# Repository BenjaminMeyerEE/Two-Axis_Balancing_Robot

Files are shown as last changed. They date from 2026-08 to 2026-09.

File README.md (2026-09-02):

# Two-Axis Balancing Robot

A robot that balances in pitch and roll. The two axes use different hardware: pitch
runs a brushless motor through a VESC over CAN, roll runs a brushed motor through an
H-bridge on a custom power board. Both close around an STM32G474 and an ICM-42688-P
IMU on a custom carrier board. Two custom 4-layer boards, designed in KiCad.

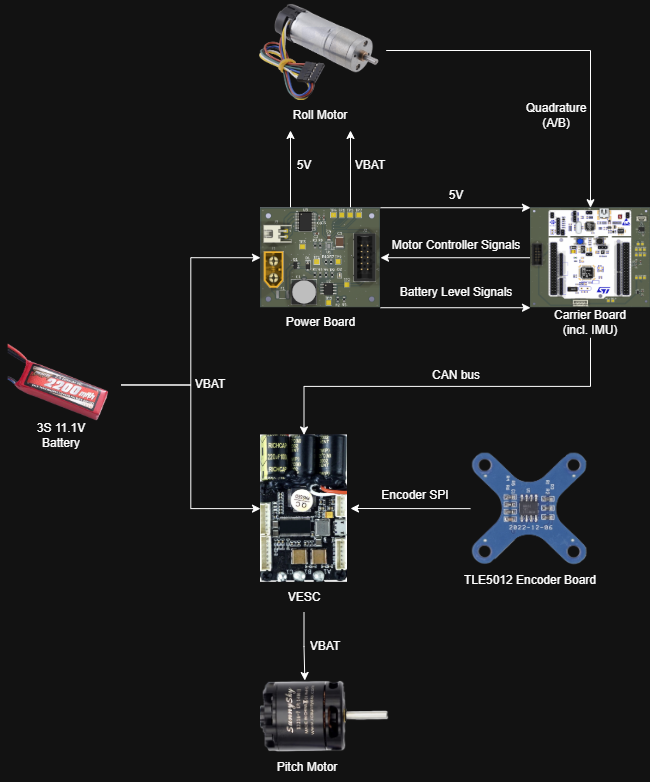
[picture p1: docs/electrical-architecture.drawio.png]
Electrical architecture


<!-- TODO
     - mechanical: CAD screenshots once the design is finished
     - the Simulink model and the LQR weight-selection model, once cleaned up
     - fp-lib-table on both boards points at C:/Users/brmey/Downloads, so footprint
       libraries won't resolve on another machine
     - the carrier render uses a Nucleo-64 F401 STEP as a stand-in; same form factor
       as the G474RE but the silkscreen says F411 if you look closely
     images are generated, see docs/regenerate-images.md
-->

## Specifications

| Parameter | Value |
|---|---|
| Axes | Pitch and roll, separate drive hardware |
| Controller | STM32G474RET6 (Nucleo-G474RE on the carrier board) |
| IMU | ICM-42688-P over SPI, both interrupt lines broken out |
| Pitch drive | Brushless motor via VESC, commanded over CAN |
| Pitch feedback | TLE5012 magnetic encoder, SPI to the VESC |
| Roll drive | Brushed motor via TB6612FNG dual H-bridge |
| Roll feedback | Quadrature encoder into the carrier board |
| Battery | 3S LiPo, 11.1 V nominal |
| Carrier board | 101.6 × 92.9 mm, 4-layer |
| Power board | 50.0 × 42.9 mm, 4-layer |

## Status

Both custom PCBs are designed and the electrical architecture is laid out. Mechanical
design is partly finished.

I simulated the pitch axis in Simulink first, and that's what pushed me away from PID and toward LQR. Wheel position and tilt are coupled through the dynamics, so tuning them as separate loops meant the two kept fighting each other — full state feedback made more sense than trying to manage that interaction by hand. What I'm working on now is deriving the equations of motion using Lagrangian mechanics, linearizing about the upright equilibrium, and designing a discrete-time LQR, using Bryson's rule to set the cost weights. This is all being done in MATLAB

## Repository layout

| Path | Contents |
|---|---|
| `hardware/two_axis_balancing_carrier/` | Carrier board KiCad project |
| `hardware/two_axis_balancing_power/` | Power board KiCad project |
| `docs/` | Architecture diagram, board renders, layer plots |

## Hardware

Both boards are 4-layer. Every copper layer below is plotted from the top and
unmirrored, so features line up between layers.

### Carrier board

101.6 × 92.9 mm. Holds the Nucleo-G474RE and everything the control loop reads.

| | |
|---|---|
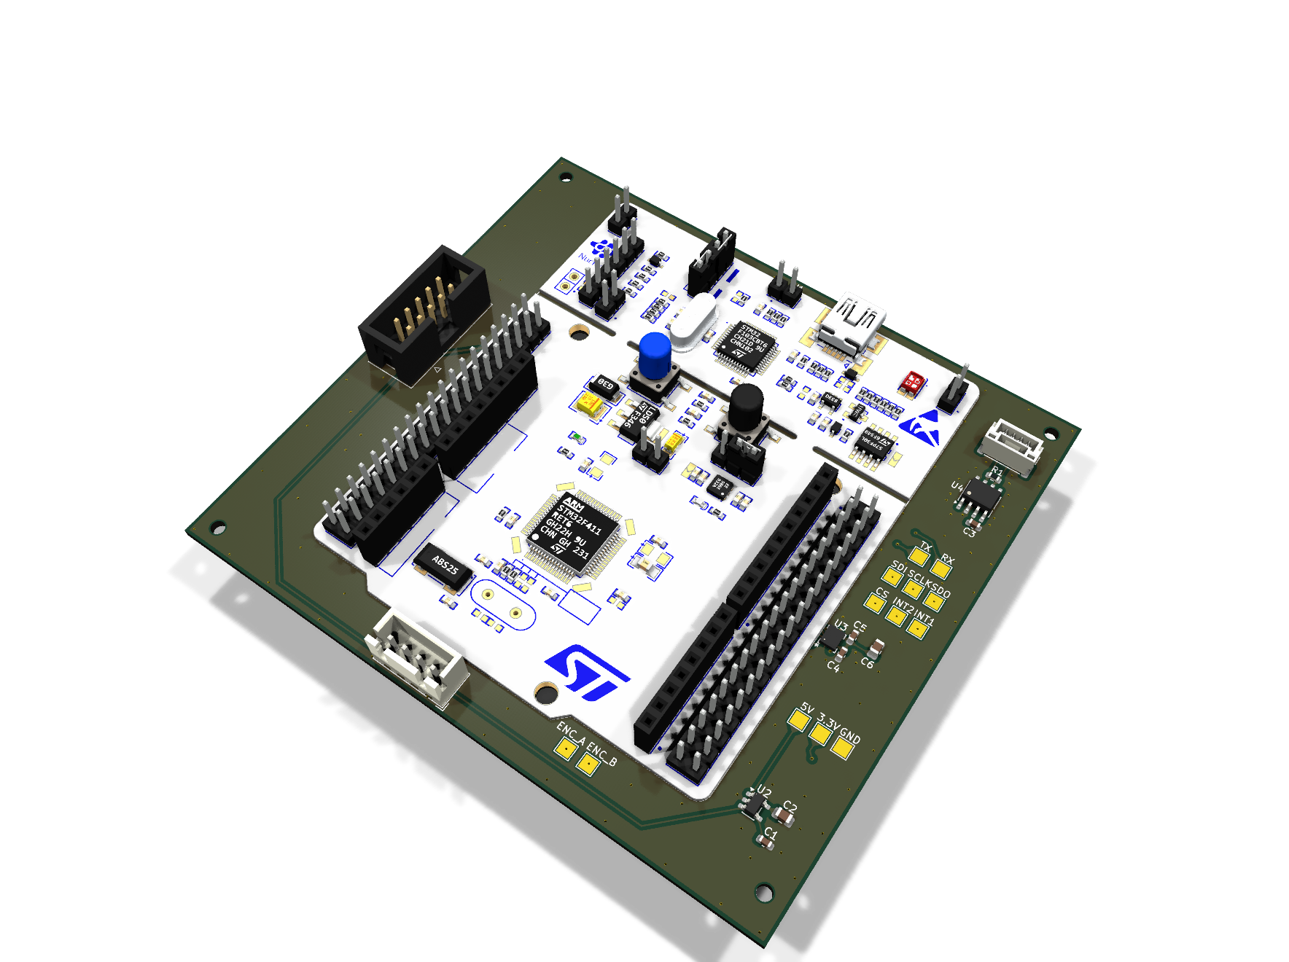
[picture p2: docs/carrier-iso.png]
Carrier board
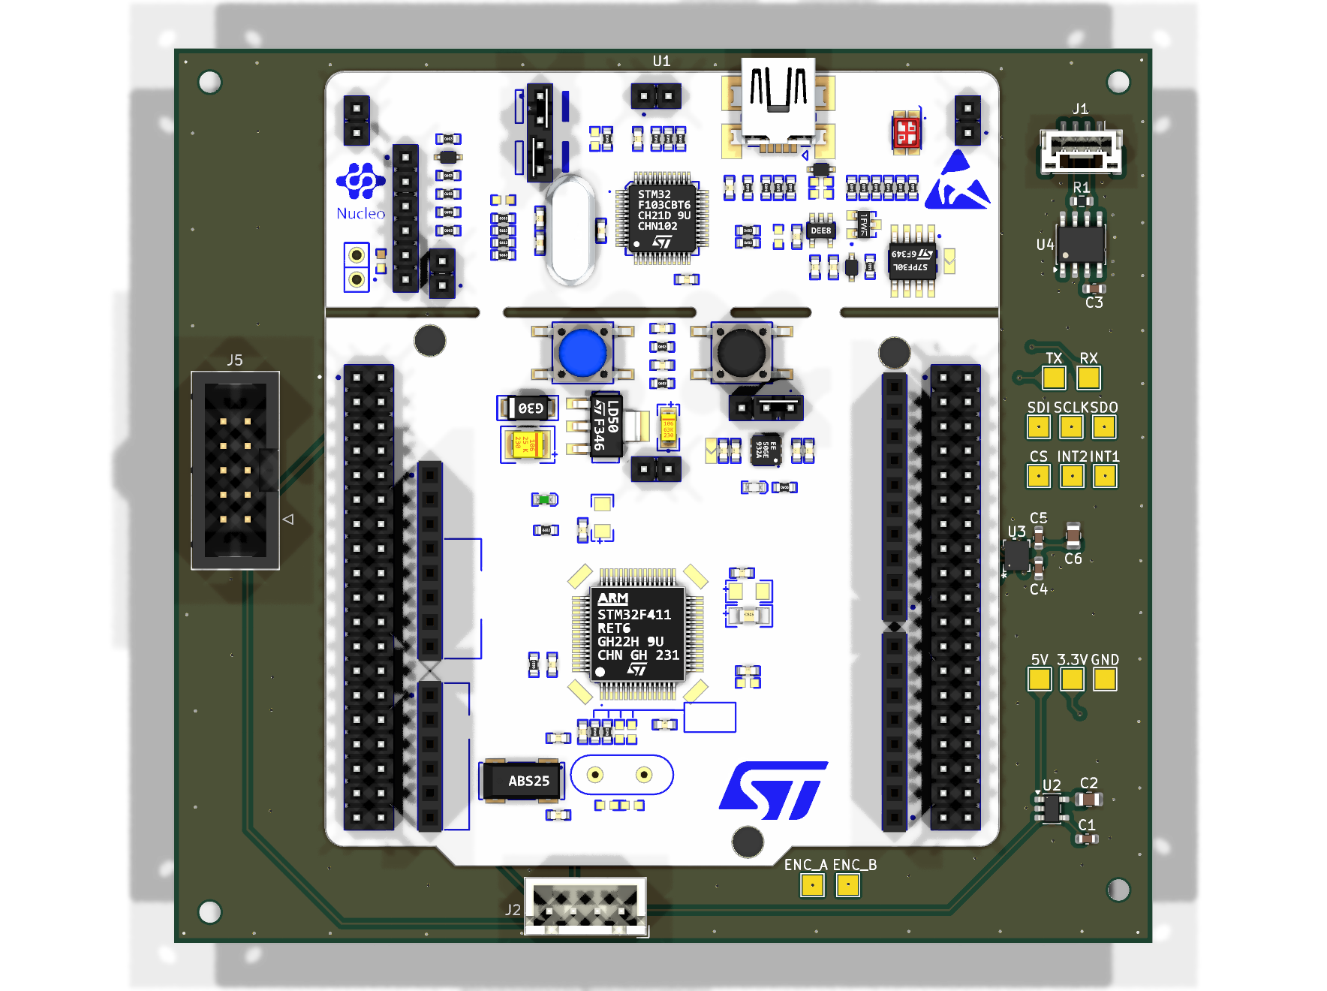
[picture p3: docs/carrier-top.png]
Carrier board, top
|  |  |

The ICM-42688-P is on SPI (`CS`, `SCLK`, `SDI`, `SDO`) with `INT1` and `INT2` brought
out, so the loop can run off data-ready rather than polling. An SN65HVD230 with 120 Ω
termination puts the board on the CAN bus to the VESC. A MIC5219-3.3 makes the 3.3 V
rail from the 5 V coming off the power board.

Roll encoder channels come in here on `ENC_A` / `ENC_B`. Motor commands (`AIN1`,
`AIN2`, `PWMA`, `STBY`) and the battery signals go back to the power board over a 2×5
IDC ribbon. There are 13 test points, and the SPI, UART, encoder and rail pads are all
labelled on the silkscreen for bring-up.

| `F.Cu` | `In1.Cu` |
|---|---|
| F.Cu | In1.Cu |

| `In2.Cu` | `B.Cu` |
|---|---|
| In2.Cu | B.Cu |

### Power board

50.0 × 42.9 mm. Takes the battery in and handles everything that touches VBAT.

| | |
|---|---|
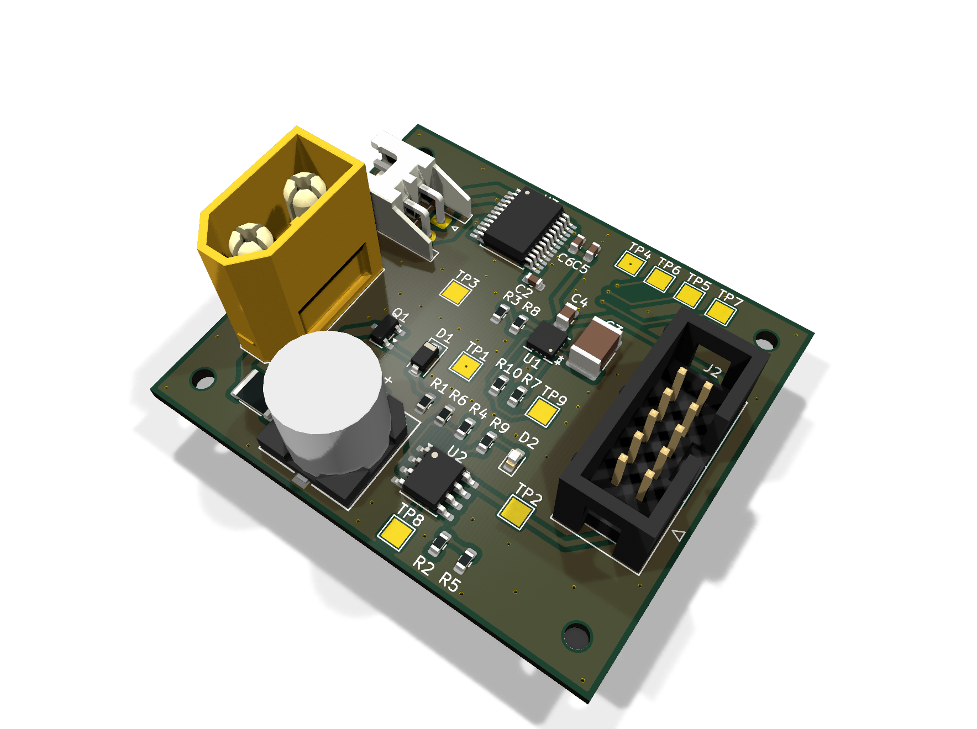
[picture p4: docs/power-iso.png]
Power board
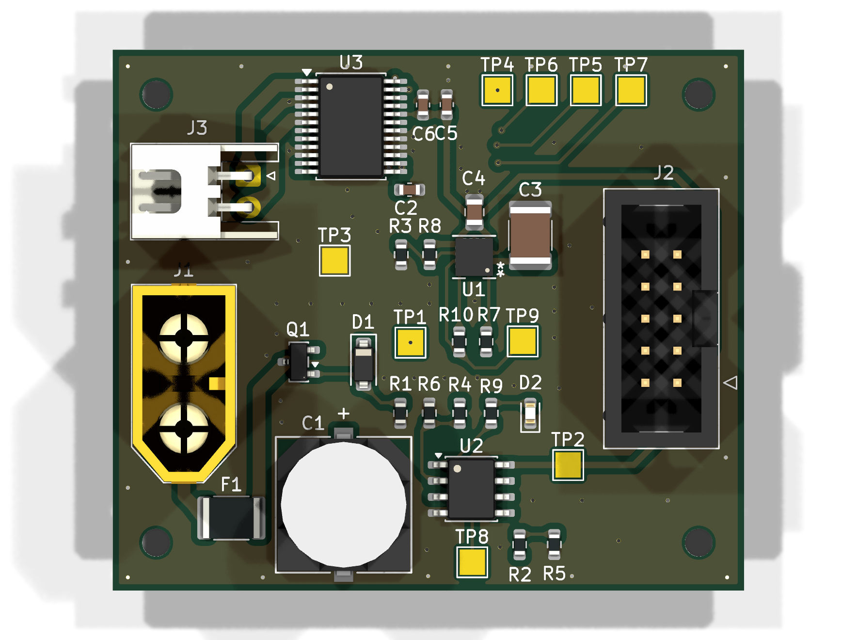
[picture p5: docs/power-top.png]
Power board, top
|  |  |

Battery comes in on an XT60, behind a 3 A fuse, an AO3401A P-channel MOSFET for
reverse polarity, and a 10 V zener. An RPL-1.0-R module makes the 5 V rail and reports
`Buck_PG` back to the MCU. A TB6612FNG dual H-bridge drives the roll motor on
`MOTOR_P` / `MOTOR_N`.

Battery monitoring is done on this board rather than in firmware. A divider gives
`BAT_LEV`, an LM393 compares it against `BAT_REF`, and `BAT_LOW` goes back to the
carrier board. The MCU sees both the raw level and a latched low flag.

| `F.Cu` | `In1.Cu` |
|---|---|
| F.Cu | In1.Cu |

| `In2.Cu` | `B.Cu` |
|---|---|
| In2.Cu | B.Cu |

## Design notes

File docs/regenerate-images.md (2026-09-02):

# Regenerating the images

Everything in `docs/` except the architecture diagram is generated from the board
files with `kicad-cli`, so it can be rebuilt after a layout change instead of
re-screenshotted.

On Windows the binary is at:

    "C:/Program Files/KiCad/10.0/bin/kicad-cli.exe"

Run from the repository root. `$N` is `power` or `carrier`, `$B` is the matching
project folder under `hardware/`.

## 3D renders

    kicad-cli pcb render -o docs/$N-iso.png --quality high --perspective \
      --rotate '-30,0,-35' --zoom 0.7 --width 1800 --height 1350 \
      --background transparent hardware/$B/$B.kicad_pcb

    kicad-cli pcb render -o docs/$N-top.png --side top --quality high \
      --width 1800 --height 1350 --background transparent \
      hardware/$B/$B.kicad_pcb

Transparent backgrounds are deliberate. They read correctly on both GitHub's light
and dark themes.

## Copper layers

One SVG per layer, with the board outline for reference:

    for lp in "F.Cu:f-cu" "In1.Cu:in1-cu" "In2.Cu:in2-cu" "B.Cu:b-cu"; do
      L="${lp%%:*}"; S="${lp##*:}"
      kicad-cli pcb export svg -o "docs/$N-layer-$S.svg" --mode-single \
        --layers "$L,Edge.Cuts" --exclude-drawing-sheet --page-size-mode 2 \
        --check-zones hardware/$B/$B.kicad_pcb
    done

Then darken the board outline, since KiCad plots `Edge.Cuts` as `#D0D2CD` which
disappears on a white page:

    sed -i 's/#D0D2CD/#555555/g' docs/*-layer-*.svg

Silkscreen is left out on purpose. KiCad plots it as `#F2EDA1`, which is effectively
invisible against GitHub's light background. `B.Cu` is not mirrored, so every layer
lines up with every other one.

## Notes

- `--check-zones` refills pours before plotting, so the layer images always match the
  current zone settings.
- Close the KiCad PCB editor first. `kicad-cli` reads from disk, and an open editor
  can overwrite the board file when it saves.
- Regenerating always shows every file as modified. Raytraced PNGs differ by a few
  hundred bytes between runs and the SVGs carry a timestamp, so use a diff of the
  drawing elements rather than `git status` to tell whether anything really changed.

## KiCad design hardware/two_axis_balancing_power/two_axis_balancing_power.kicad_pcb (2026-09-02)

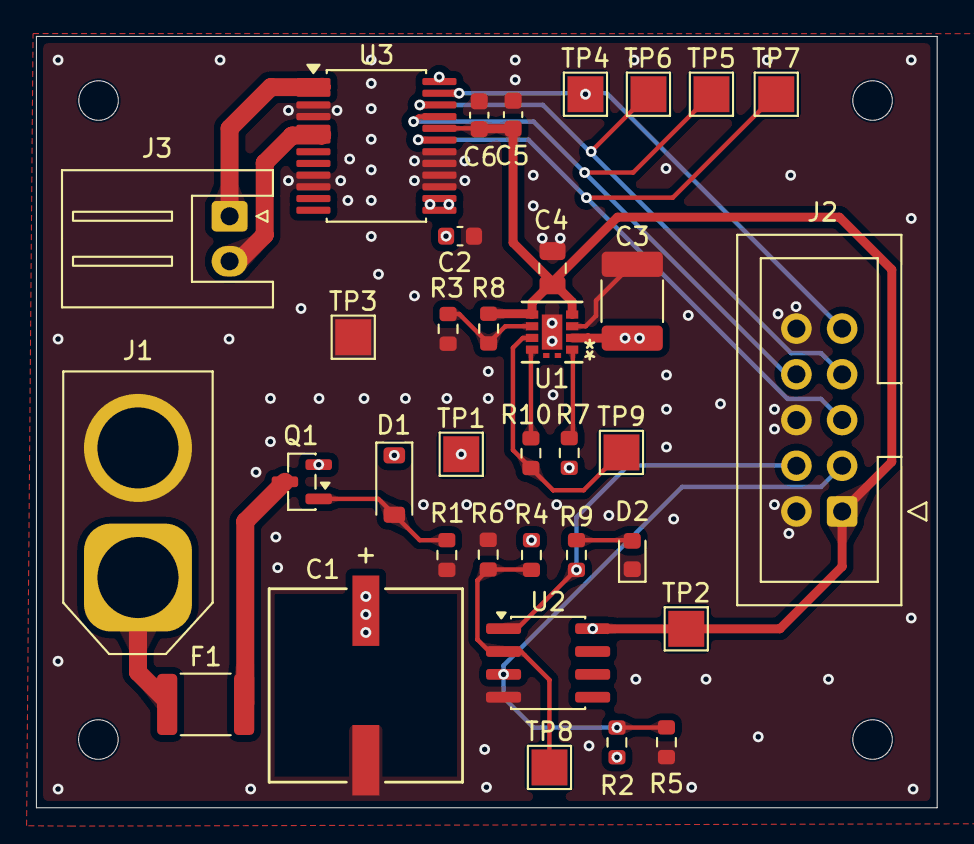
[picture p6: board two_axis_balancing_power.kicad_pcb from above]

Board: 4 copper layers, 50.0 x 42.9 mm, 35 parts (0 on the bottom side), 20 nets.

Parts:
C1: 470uF; PCAP_10x10-ELECT_NCA
C2, C6: 100nF; C_0603_1608Metric
C3: 20uF; C_1812_4532Metric
C4: 22uF; C_0805_2012Metric
C5: 10uF; C_0603_1608Metric
D1: 10V; D_SOD-123
D2: LED; LED_0603_1608Metric
F1: 3A; Fuse_1812_4532Metric
J1: Conn_01x02; AMASS_XT60-M_1x02_P7.20mm_Vertical
J2: Conn_02x05; IDC-Header_2x05_P2.54mm_Vertical
J3: Conn_01x02; JST_XH_S2B-XH-A_1x02_P2.50mm_Horizontal
Q1: AO3401A; SOT-23
R1, R4, R5: 10kR; R_0603_1608Metric
R2: 47kR; R_0603_1608Metric
R3: 220kR; R_0603_1608Metric
R6: 5.9kR; R_0603_1608Metric
R7, R10: 100kR; R_0603_1608Metric
R8: 1613kR; R_0603_1608Metric
R9: 220R; R_0603_1608Metric
TP1, TP2, TP3, TP4, TP5, TP6, TP7, TP8, TP9: TestPoint; TestPoint_Pad_2.0x2.0mm
U1: RPL-1.0-R; 11L-LGA-M_RPL-1_RCP
U2: LM393; SOIC-8_3.9x4.9mm_P1.27mm
U3: TB6612FNG; SSOP-24_5.3x8.2mm_P0.65mm

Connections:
+5V: C4.2, C5.2, C6.2, J2.1, R4.2, R8.2, TP2.1 (1_1), U1.4 (VOUT), U1.5 (VOUT), U2.8 (V+), U3.20 (VCC)
/AIN1: J2.8, TP5.1 (1_1), U3.21 (AIN1)
/AIN2: J2.7, TP6.1 (1_1), U3.22 (AIN2)
/BAT_LEV: J2.3, R2.1, R5.1, U2.3 (+)
/BAT_LOW: J2.4, R9.2, U2.1
/BAT_REF: R4.1, R6.1, TP8.1 (1_1), U2.2 (-)
/Buck_PG: R10.2, TP9.1 (1_1), U1.7 (PG)
/MOTOR_N: J3.2, U3.5 (AO2), U3.6 (AO2)
/MOTOR_P: J3.1, U3.1 (AO1), U3.2 (AO1)
/PWMA: J2.9, TP4.1 (1_1), U3.23 (PWMA)
/STBY: J2.5, TP7.1 (1_1), U3.19 (STBY)
GND: C1.2, C2.2, C3.1, C4.1, C5.1, C6.1, D2.1 (K), J1.2, J2.2, J2.6, J2.10, R1.2, R3.1, R5.2, R6.2, TP3.1 (1_1), U1.3 (PGND), U1.11 (TP), U2.4 (V-), U3.3 (PGND1), U3.4 (PGND1), U3.9 (PGND2), U3.10 (PGND2), U3.15 (PWMB), U3.16 (BIN2), U3.17 (BIN1), U3.18 (GND)
unnamed: D1.2 (A), Q1.1 (G), R1.1
unnamed: D2.2 (A), R9.1
unnamed: F1.1, J1.1
unnamed: F1.2, Q1.3 (D)
unnamed: R7.2, U1.1 (CTRL)
unnamed: R3.2, R8.1, U1.6 (FB)
unnamed: R10.1, U1.8 (VCC)
VBAT: C1.1, C2.1, C3.2, D1.1 (K), Q1.2 (S), R2.2, R7.1, TP1.1 (1_1), U1.2 (VIN), U3.13 (VM2), U3.14 (VM3), U3.24 (VM1)

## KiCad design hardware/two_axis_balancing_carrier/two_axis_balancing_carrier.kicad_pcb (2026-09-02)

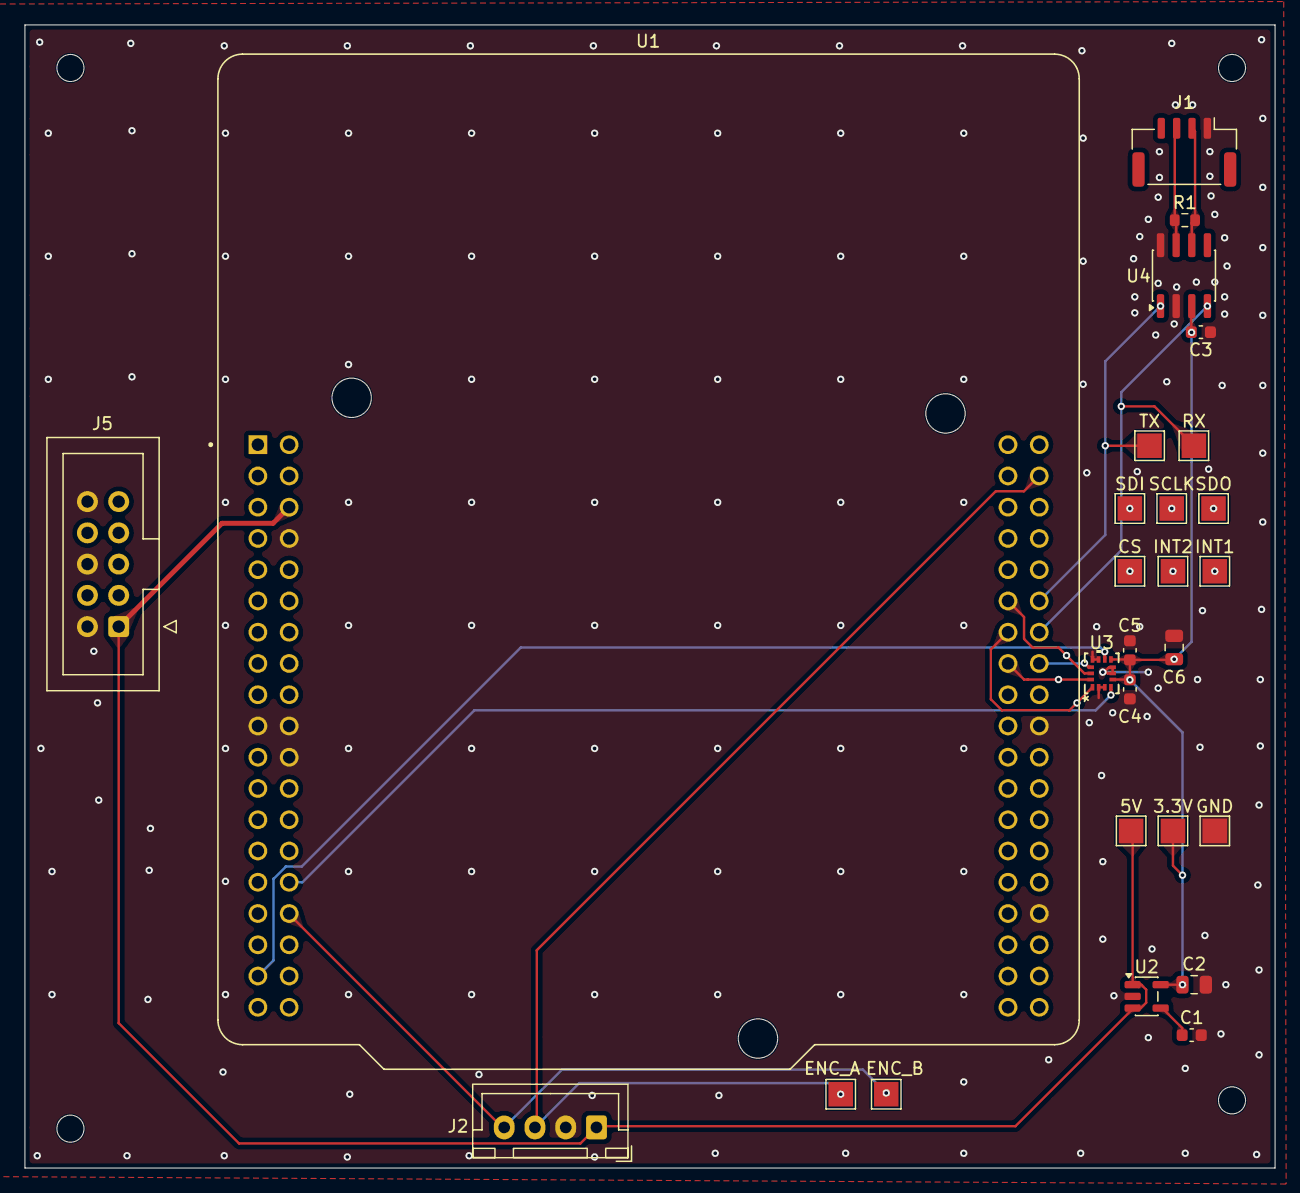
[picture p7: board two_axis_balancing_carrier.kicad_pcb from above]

Board: 4 copper layers, 101.6 x 92.9 mm, 27 parts (0 on the bottom side), 22 nets.

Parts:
3.3V, 5V: TestPoint; TestPoint_Pad_2.0x2.0mm
C1: 470pF; C_0603_1608Metric
C2, C6: 2.2uF; C_0805_2012Metric
C3, C5: 100nF; C_0603_1608Metric
C4: 10nF; C_0603_1608Metric
CS: TestPoint; TestPoint_Pad_2.0x2.0mm
ENC_A: TestPoint; TestPoint_Pad_2.0x2.0mm
ENC_B: TestPoint; TestPoint_Pad_2.0x2.0mm
GND: TestPoint; TestPoint_Pad_2.0x2.0mm
INT1, INT2: TestPoint; TestPoint_Pad_2.0x2.0mm
J1: Conn_01x03; JST_GH_BM04B-GHS-TBT_1x04-1MP_P1.25mm_Vertical
J2: Conn_01x04; JST_XH_B4B-XH-A_1x04_P2.50mm_Vertical
J5: Conn_02x05; IDC-Header_2x05_P2.54mm_Vertical
R1: 120R; R_0603_1608Metric
RX: TestPoint; TestPoint_Pad_2.0x2.0mm
SCLK: TestPoint; TestPoint_Pad_2.0x2.0mm
SDI: TestPoint; TestPoint_Pad_2.0x2.0mm
SDO: TestPoint; TestPoint_Pad_2.0x2.0mm
TX: TestPoint; TestPoint_Pad_2.0x2.0mm
U1: NUCLEO-G474RE; MODULE_NUCLEO-G474RE
U2: MIC5219-3.3YM5; SOT-23-5
U3: ICM-42688-P; LGA14_2P5X3X0P91_TDK
U4: SN65HVD230; SOIC-8_3.9x4.9mm_P1.27mm

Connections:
+3.3V: 3.3V.1 (1_1), C2.1, C3.1, C4.2, C5.1, C6.1, U2.5 (OUT), U3.5 (VDDIO), U3.8 (VDD), U4.3 (VCC)
+5V: 5V.1 (1_1), J2.1, J5.1, U1.CN7_6 (E5V), U2.1 (IN), U2.3 (EN)
/AIN1: J5.8, U1.CN7_23 (PC13)
/AIN2: J5.7, U1.CN7_25 (PC14)
/BAT_LEV: J5.3, U1.CN7_28 (PA0)
/BAT_LOW: J5.4, U1.CN7_37 (PC3)
/CANH: J1.3, R1.1, U4.7 (CANH)
/CANL: J1.2, R1.2, U4.6 (CANL)
/CS: CS.1 (1_1), U1.CN10_16 (PB12), U3.12 (AP_CS)
/ENC_A: ENC_A.1 (1_1), J2.3, U1.CN10_4 (PC6)
/ENC_B: ENC_B.1 (1_1), J2.4, U1.CN7_32 (PA4)
/INT1: INT1.1 (1_1), U1.CN7_30 (PA1), U3.4 (INT1/INT)
/INT2: INT2.1 (1_1), U1.CN7_35 (PC2), U3.9 (INT2/FSYNC/CLKIN)
/PWMA: J5.9, U1.CN7_38 (PC0/PA15)
/RX: RX.1 (1_1), U1.CN10_14 (PA11), U4.4 (R)
/SCLK: SCLK.1 (1_1), U1.CN10_11 (PA5), U3.13 (AP_SCL/AP_SCLK)
/SDI: SDI.1 (1_1), U1.CN10_15 (PA7), U3.14 (AP_SDA/AP_SDIO/AP_SDI)
/SDO: SDO.1 (1_1), U1.CN10_13 (PA6), U3.1 (AP_SDO/AP_AD0)
/STBY: J5.5, U1.CN7_27 (PC15)
/TX: TX.1 (1_1), U1.CN10_12 (PA12), U4.1 (D)
GND: C1.2, C2.2, C3.2, C4.1, C5.2, C6.2, GND.1 (1_1), J1.1, J2.2, J5.2, J5.6, J5.10, U1.CN7_8 (GND_CN7_8), U1.CN7_19 (GND_CN7_19), U1.CN7_20 (GND_CN7_20), U1.CN7_22 (GND_CN7_22), U1.CN10_20 (GND_CN10_20), U1.CN10_32 (AGND), U2.2 (GND), U3.2 (RESV), U3.3 (RESV), U3.6 (GND), U3.7 (RESV), U3.10 (RESV), U3.11 (RESV), U4.2 (GND), U4.8 (Rs)
unnamed: C1.1, U2.4 (BP)

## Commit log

2026-06-01 Two-axis balancing robot: carrier and power boards
    [Carrier-Board.kicad_sch, Power-Board.kicad_sch, two_axis_balancing_carrier.kicad_pcb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]
2026-06-01 Fixed file structure
    [Carrier-Board.kicad_sch, Power-Board.kicad_sch, two_axis_balancing_power.kicad_pcb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]
2026-06-02 Power board topology finished and carrier board started
    [two_axis_balancing_carrier.kicad_sch]
2026-06-02 Finished topology
    [two_axis_balancing_carrier.kicad_sch, two_axis_balancing_power.kicad_sch]
2026-06-08 Sized passives
    [two_axis_balancing_carrier.kicad_sch, two_axis_balancing_power.kicad_sch]
2026-06-09 Started pcb design
    [two_axis_balancing_power.kicad_pcb, two_axis_balancing_power.kicad_sch]
2026-06-17 Almost finished pcb
    [two_axis_balancing_power.kicad_pcb, two_axis_balancing_power.kicad_sch]
2026-06-17 Finished pcb
    [two_axis_balancing_power.kicad_pcb]
2026-06-18 Carrier schematic finished and power board polished
    [two_axis_balancing_carrier.kicad_sch, two_axis_balancing_power.kicad_pcb]
2026-06-19 Power actually finished; carrier pcb started
    [two_axis_balancing_carrier.kicad_pcb, two_axis_balancing_carrier.kicad_sch, two_axis_balancing_power.kicad_pcb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]
2026-06-27 Carrier layout finished
    [two_axis_balancing_carrier.kicad_pcb, two_axis_balancing_carrier.kicad_sch, two_axis_balancing_power.kicad_pcb]
2026-08-09 Connectors need changing
    [two_axis_balancing_carrier.kicad_pcb, two_axis_balancing_carrier.kicad_sch]
2026-08-09 Finished carrier prototype
    [two_axis_balancing_carrier.kicad_pcb, two_axis_balancing_carrier.kicad_sch]
2026-08-09 Small fix
    [two_axis_balancing_carrier.kicad_pcb]
2026-08-09 More small fixes
    [two_axis_balancing_carrier.kicad_pcb]
2026-09-02 Reorganize into hardware/ and docs/, add README
    [two_axis_balancing_carrier.kicad_pcb, two_axis_balancing_carrier.kicad_sch, two_axis_balancing_power.kicad_pcb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]
2026-09-02 Add missing 3D models for the fuse, IMU and power module
    [two_axis_balancing_carrier.kicad_pcb, two_axis_balancing_power.kicad_pcb]
2026-09-02 Write project README with board renders and layer plots
2026-09-02 Zoom out isometric renders to fit the full boards
2026-10-15 Fixed issue with battery monitoring functionality
2026-10-18 Finished MCU Carrier Schematic
2026-10-20 Started rev 2 of carrier board, mainly swapping the dev board for a bare mcu
